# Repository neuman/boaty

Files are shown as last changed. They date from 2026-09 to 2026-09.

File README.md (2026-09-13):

# boaty

A 3D-printed RC displacement boat, 480 mm LOA, developed from one screenshot of a
hull-design tool using [atompipe](https://github.com/neuman/atompipe).

**Start here:** [`docs/readiness.md`](docs/readiness.md) — what is proven, what is
assumed, and what only a real boat in real water can settle.

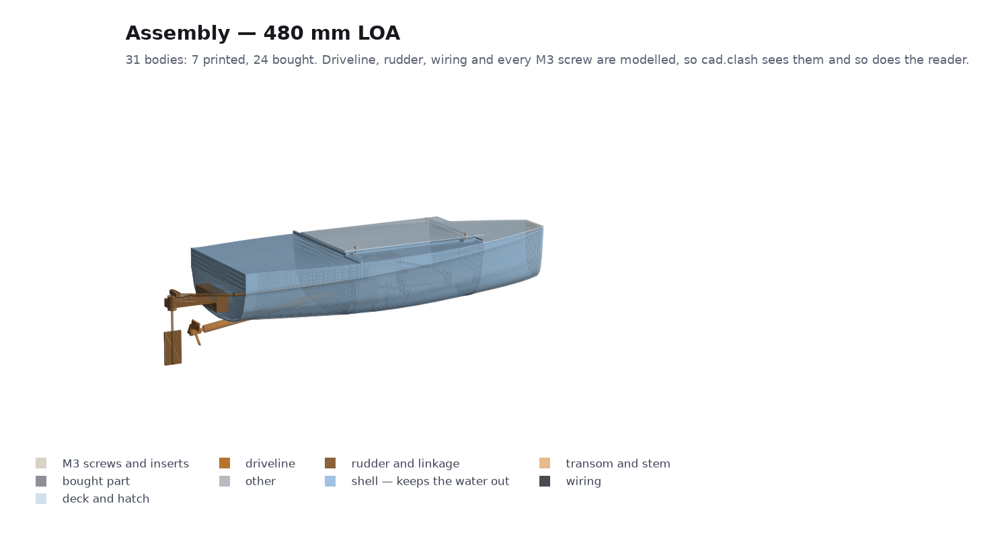
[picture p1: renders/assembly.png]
The assembly


<sub>19 bodies: 13 printed, 6 bought parts shown where they sit. Renders are
generated from the same STLs the gates measure — `python tools/render.py`.</sub>

| | |
|---|---|
| [`docs/BUY.md`](docs/BUY.md) | what to order, with prices and ASINs |
| [`docs/PRINT.md`](docs/PRINT.md) | what to print (**7 parts, 4 beds**), in what orientation, every screw, every hole to drill |
| [`docs/BUILD.md`](docs/BUILD.md) | the assembly order, arranged so mistakes stay cheap |
| [`docs/decisions.md`](docs/decisions.md) | every design decision and what LOST |
| [`FRICTION.md`](FRICTION.md) | an unflattering log of using the tool |

## The finding that shaped everything

The hull in the screenshot is 300 mm long and **displaces 73 grams at the waterline
the design tool drew**. The parts alone weigh 591 g. That waterline was a slider
position, not a loading condition.

Displacement scales as the cube of length while a motor, an ESC, a servo, a receiver
and a battery do not scale at all, so the hull is scaled 1.6x to 480 mm and the FORM
is untouched — every offset is the traced one times 1.6. At that size it floats at
29.6 mm draft with 27.3 mm of freeboard after trim, and 70% of its moulded volume in
reserve.

## What it looks like

| | |
|---|---|
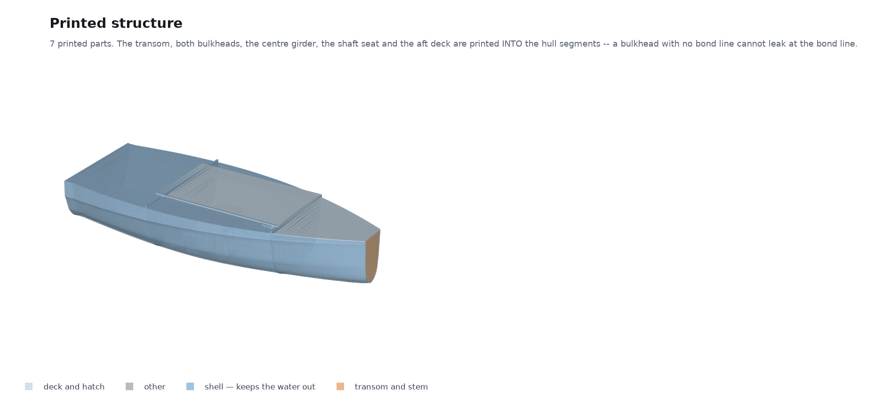
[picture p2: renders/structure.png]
Printed structure
|  | **The 13 printed parts.** Bulkheads and the centre girder divide the bilge into 53 mm cells, which is what holds the free-surface correction to 4.2 mm of GM. |
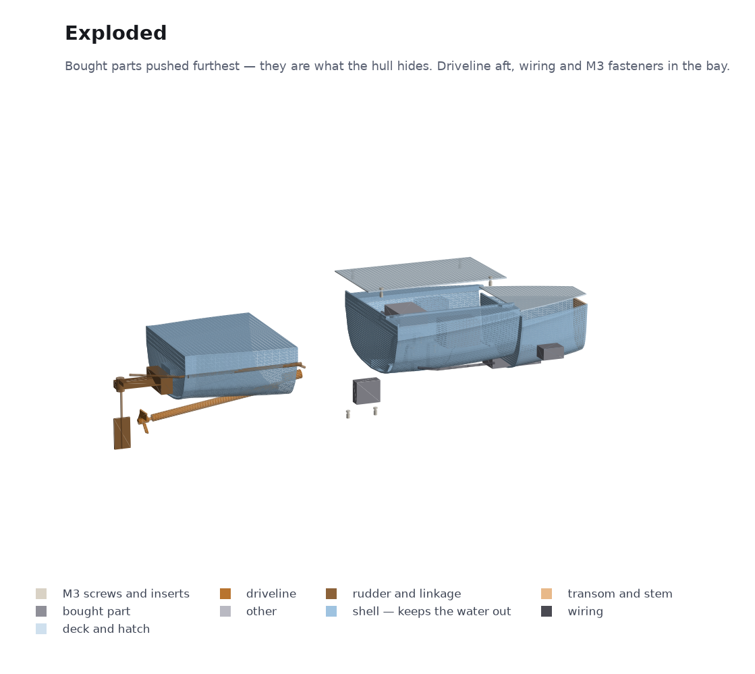
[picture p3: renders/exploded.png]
Exploded
|  | **Exploded.** The bought parts are pushed furthest because they are what the hull hides — and where the first version put the motor, the battery and the girder in the same space. |
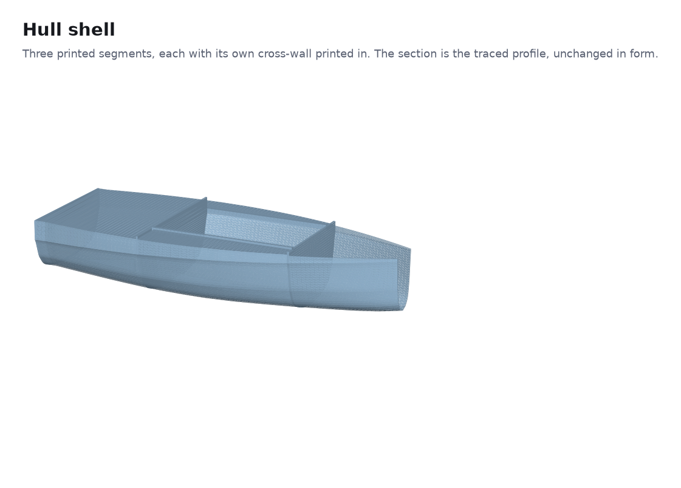
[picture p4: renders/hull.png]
Hull shell
|  | **The hull shell**, in three printed segments. The section is the traced profile, unchanged in form and scaled 1.6x. |
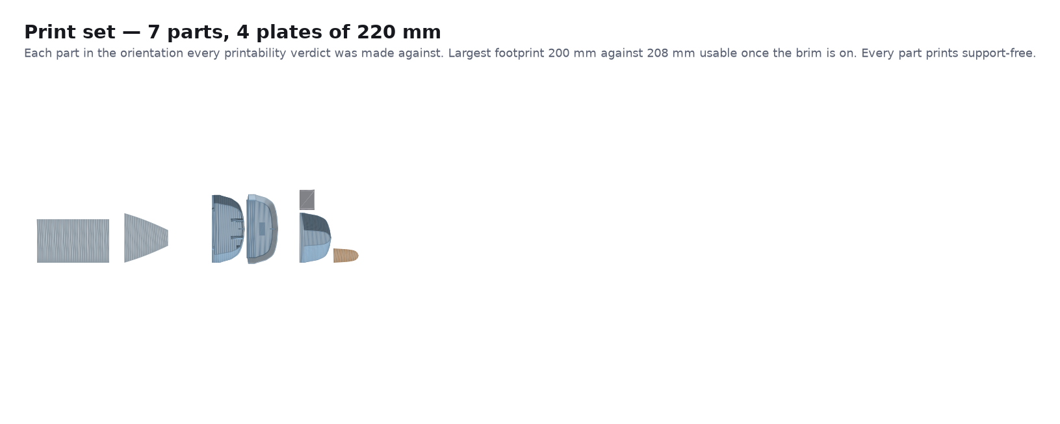
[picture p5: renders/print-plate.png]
Print set
|  | **Eight plates, not one.** Two parts are 190 and 186 mm wide, so they share a 220 mm bed with nothing. |

## Seven parts, two glued joints

The transom, both watertight bulkheads, the centre girder, the shaft seat and the aft
deck are printed INTO the hull segments rather than glued on. That is not tidiness: a
bulkhead with no bond line cannot leak at the bond line, and watertightness is the
top physical risk on the whole boat. It works because each segment prints standing on
a transverse face with its one solid cross-wall ON THE BED — put a cross-wall at the
far end of a segment instead and it becomes a 186 mm plate the print has to bridge.

Two merges were rejected and both are in the decision log: the stem cap, and the bow
deck. Both would have roofed an open cavity at the top of a print, and both being
separate is also what leaves the bow compartment open until its foam and interior
epoxy are in.

## Why the hull is in three pieces

Because a one-piece hull does not exist at any length that floats. On the
220×220×250 machine this project targets, an exhaustive orientation search against
the real hull surface gives:

| | |
|---|---|
| largest hull that prints in ONE piece | **321 mm LOA** |
| shortest hull that floats the payload with 25 mm freeboard | **376 mm LOA** |
| payload a one-piece 321 mm hull could carry | 245 g, against 630 g of fixed hardware |
| build volume a one-piece 480 mm hull needs | **336 × 336 × 336 mm** |

Splitting horizontally at the waterline does not help: the binding dimension is
LENGTH, and removing the topsides shrinks the required box by 1.2%. Two segments is
blocked on sourcing, not printing — it needs a 260 mm stuffing tube and the kit on the
BOM has a 200 mm one. All three rejections are in the decision log with their numbers.

## One hole below the waterline

The driveline, the rudder, twelve M3 screws, ten brass inserts and four wire runs are
all modelled as solids, so `cad.clash` sees them and so does the render. Every boss is
blind except the two that bolt the rudder bracket to the transom.

`boat.hull_penetrations` enumerates every hole through the hull shell or a watertight
bulkhead, states how each is sealed, and refuses more than one below the loaded
waterline — comparing against the waterline the hydrostatics produced on that run, not
a number typed beside it. There is exactly one: the propeller shaft, which is
unavoidable because the propeller has to be driven from inside.

The gate found a second one the minute it existed — the same stuffing tube also
crosses the aft bulkhead, 9 mm under water, and nothing had ever said so.

## The gate that found the hole in the method

Every geometry gate in every installed pack checks that things do **not** touch, or
that one solid is well formed. None of them can express an absence. So the boat
shipped a revision whose rudder had no stock and no tiller arm, whose blade hung 43 mm
below its own bracket attached to nothing, and whose pushrod stopped 11 mm short of
what it was pushing — with every gate green.

That idea is now `cad.assembly_connected` in the `cad-solid` pack, with the question
turned around: instead of checking chains somebody declared, it builds the contact
graph from the geometry and asks whether **every part is held by something**. The
declared-pairs version found nothing on this project; the coverage version immediately
found the on/off switch floating 5.5 mm from the nearest part, held by tape that
existed only in my head.

The project's own copy has been retired — it duplicated the pack, measured worse, and
depended on `rtree`, which this project never declared. Where `rtree` was missing every
gap came back `NaN`, and `NaN` defeats every comparator, so the gate written to prove
the steering was connected was the one gate that could neither pass nor fail. The
project now declares its dependencies in [`requirements.txt`](requirements.txt) and
needs no `rtree` at all.

See [`FRICTION.md`](FRICTION.md) items 26 and 30-33; they are the most transferable
things in this repository.

## Layout

```
brief/            the screenshot this all came from
inputs/           evidence, and what was read out of it
tools/            trace_hull_profile.py   screenshot -> hull offsets
                  emit_docs.py            model -> BUY/PRINT/BUILD
                  render.py               STLs -> renders/ (no GPU, no display)
renders/          generated. Regenerate with tools/render.py.
model/            hullform.py  the hull surface and its integrals
                  geometry.py  offsets -> meshes
                  boat.py      THE MODEL. Everything else is generated from it.
gates/            the seven checks no installed pack covers
selftest/         a known-bad input for each of those seven
build/            generated STLs (assembly frame) and build/print/ (bed frame)
docs/             generated: readiness, buy, print, build, decisions
site/             the same ledger as a page: atompipe site serve
```

## Running it

```sh
.venv/bin/atompipe check              # tier 0, under a second
.venv/bin/atompipe check --tier 1     # the full sweep, including meshes
.venv/bin/atompipe gate selftest      # prove every gate can still fail
.venv/bin/atompipe report             # the readiness report
.venv/bin/atompipe why hull_scale     # one parameter's whole history
.venv/bin/atompipe site serve         # the ledger as a page
.venv/bin/python tools/emit_docs.py   # regenerate the buy/print/build docs
```

**Generated files are outputs.** Do not hand-edit anything in `build/` or `docs/`;
change `model/boat.py` and re-run.

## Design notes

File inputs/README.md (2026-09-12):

# inputs/ — the evidence this design is built on

Put real files here. Hand sketches, photos of the thing you'd buy instead, CAD
you already have, datasheet PDFs, caliper readings, log files. Intake is not only
a conversation: the numbers that matter usually arrive as a photo of a napkin.

Use `atompipe ingest <path>` rather than copying by hand — it files the artifact
in the right bucket, hashes it, and registers it in the ledger so a changed input
can mark a claim STALE. Then use `atompipe extract` to record what you actually
read out of it:

    atompipe ingest inputs/sketches/hull.png --desc "midship section, dimensioned"
    atompipe extract hull-png --what "hull beam at midship reads 148 mm" \
                              --grounds beam_mm

**An artifact nobody extracted from is decoration.** A file sitting in this
directory grounds nothing, proves nothing, and will not stop anyone from
re-litigating a number two months from now. `atompipe inputs --unextracted`
lists the decorations.

## Buckets

- `sketches/`      hand drawings, napkin diagrams, whiteboard photos
- `references/`    photos of existing products, teardowns, prior art
- `cad/`           STL, STEP, 3MF, f3d, KiCad, gerbers
- `screenshots/`   a UI, a config screen, a vendor page, another tool's output
- `datasheets/`    component and material datasheets (usually PDF)
- `specs/`         written specs, briefs, RFQs, requirements — and published
                   standards (IPC, ASTM, NEC); a standard is a requirements doc
- `measurements/`  calipers, scales, meters: numbers off the real world
- `data/`          CSV, logs, test results, and anything that fits nowhere else

The directory an artifact sits in is a hint the pipeline reads, so a photo in
`references/` is treated as prior art and the same photo in `sketches/` is
treated as your own drawing. File accordingly.

Empty buckets do not survive a `git clone` (git does not track empty
directories). `atompipe ingest` recreates whichever one it needs.

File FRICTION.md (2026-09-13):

# Friction log — building an RC boat with atompipe

Blunt notes, written as I went. Timestamps are rough ordering, not wall clock.
Quoted text is real terminal output.

---

## 0. Before running anything

**Friction: the skill tells you to set `$CLAUDE_PLUGIN_ROOT` and it is not set.**

`skills/atompipe/SKILL.md` says:

```sh
export PYTHONPATH="$CLAUDE_PLUGIN_ROOT/src:$PYTHONPATH"
alias atompipe='python3 -m atompipe'
```

`CLAUDE_PLUGIN_ROOT` is empty in my environment, so that line silently exports
`PYTHONPATH=/src:` and the next command fails with a plain ImportError. It is not
wrong, it is just that the four-line ladder of "try these in order" is written for a
human reading output, and an agent that pastes the wrong rung gets a confusing
failure one step later. In this project there is a venv shim
(`.venv/bin/atompipe`), which works and is what I used — but nothing in the docs
told me to look for that; the user did.

**Suggestion:** `atompipe doctor` should be runnable *before* you have a working
atompipe. A one-line bootstrap that finds the spine would remove the whole ladder.

## 1. `atompipe packs install` does not exist

`skills/atompipe/SKILL.md` says, twice, in the section about clearing a BLOCKED claim:

> Run `atompipe packs install <pack>` for the recipe, install the tool, and re-run.

There is no `install` subcommand:

```
$ atompipe packs install fluids-analytic
usage: atompipe packs [-h] <sub> ...
atompipe packs: error: argument <sub>: invalid choice: 'install'
  (choose from 'list', 'show', 'validate', 'add', 'remove')
```

The verb is `add`. Small, but it is in the *one* document an agent is told to read
before doing anything, in the paragraph about the failure mode the tool cares most
about (a BLOCKED claim left lying around), so it is the worst possible place for it.

Also: `atompipe packs list` prints `* = installed in this project (0 of 7
discoverable)` — but nothing on that screen tells you that "discoverable" and
"installed" are different states, or that `add` is what moves a pack between them.
I only found out because `atompipe gate list` said `no gates registered` after I had
already read three PACK.md files and assumed they were live. **For a while I thought
I had a working gate set and I had zero.** That is exactly the "looks validated and
is not" failure the method is about, one level up, in the tool itself.

## 2. `atompipe doctor` prints `[FAIL]` and exits 0

```
$ atompipe doctor; echo "exit=$?"
[ok  ] python             3.12.3 ...
[ok  ] spine              atompipe 0.1.0 ...
[FAIL] project            no .atompipe/ in ... — run `atompipe init`
3 checks — 1 failing, 0 warning(s)
exit=0
```

METHOD.md rule 4 is "Validators are gates, not loggers — a validator that prints a
problem and exits 0 is a decoration." `doctor` is the tool's own front door and it
is a decoration by its own definition. It cost me nothing here because I read the
output, but anything scripting `atompipe doctor && ...` gets a false green.

## 3. Packs are "discoverable" and "installed" and nothing says they are different

`atompipe packs list` shows seven packs and a footer:

```
* = installed in this project (0 of 7 discoverable)
```

Nothing on that screen explains that a discoverable pack contributes nothing, or that
`packs add` is what changes it. I had read three PACK.md files and built a mental model
of which gates I was going to use before `atompipe gate list` told me:

```
no gates registered. Install a pack (`atompipe packs`) or write gates/<name>.py in this project.
```

**For about twenty minutes I believed I had a working gate set and I had zero.** That
is the tool's own headline failure mode — looking validated and not being — reproduced
one level up, in the tool.

Suggestion: `atompipe status` should say "0 gates available, 7 packs discoverable but
not added" in the same breath, or `init` should offer to add the packs whose
claim_classes match the claims already in the ledger.

## 4. `atompipe check` warned me about a name collision I would never have found

Credit where it is due, and this is the single most valuable thing the tool did:

```
warning: model and build() disagree on min_freeboard_mm:
         config 25.0 vs build() 31.808492225817865 — gates read the config value
```

I had used one name for the freeboard THRESHOLD and for the freeboard MEASUREMENT.
The gate would have compared against 25.0 while the report printed 31.8, and both
numbers are plausible, and the error is in the reassuring direction. Nothing else in
my process would have caught it. This is rule 6 mechanised and it works.

## 5. Two packs collide on `bbox_mm` and only one can win

`fdm-print` reads `bbox_mm` for the single PART it is judging. `cad-solid` reads
`bbox_mm` for the ASSEMBLY. One projection cannot mean both.

Publishing the assembly there:

```
[FAIL] fdm.bed_fit : 480x186x87 mm vs 208x208 usable (220x220 bed - 2x6.0 brim) x 250 Z
```

— a 480 mm boat measured against a 220 mm printer bed. Not publishing it:

```
[skip] cad.bounding : bbox_mm is absent — nothing to compare, so nothing is claimed
```

`fdm-print` also accepts `bbox`, and I tried publishing the part under `bbox` and the
assembly under `bbox_mm`, on the theory that the more specific key would win. It does
not: **`bbox_mm` is resolved before `bbox`**, which is undocumented and is the opposite
of what the key names suggest. So `fdm.bed_fit` — the gate that answers "can I build
this at home", which is the whole brief — kept the key, `cad.bounding` skips, and I
wrote a project gate `boat.envelope` to cover the claim instead.

**This is a real design bug in the pack ecosystem, not a mistake I made.** Two packs
that are both in the tool's own default set cannot be used together on a project that
has an assembly and printed parts, which is every mechanical project. A pack-scoped
key namespace (`fdm.bbox_mm`, `cad.bbox_mm`) would fix it. `atompipe doctor` could
detect it: it knows which packs are installed and could diff their key vocabularies.

## 6. `atompipe doctor` prints `[FAIL]` and exits 0

Already noted above. Worth repeating because it never got better: across the whole
session, `doctor` was the command the docs told me to run when confused, and its exit
code never reflected its own findings.

## 7. `claim edit` takes the build lock

Running claim edits while a `gate selftest` was in progress:

```
error: another atompipe run (pid 724928) holds
/home/neuman/Documents/work/boaty/.atompipe/build.lock — wait for it to finish
```

Correct behaviour for a lock, and the message is good. But **`claim edit` does not
build anything** — it edits a row in the ledger — and five claim edits silently did
not apply while I moved on believing they had. The failure is visible in stderr and
invisible in the result. A finer-grained lock, or a `--wait` flag, would help. So
would a non-zero exit code, which would have stopped my script.

## 8. A param record outlives the param

After I removed a derived key from `build()`, `atompipe status` kept reporting it:

```
standing: 1 param with no rationale
undefended params: min_freeboard_mm — no rationale recorded
```

The key is not in the model any more, by grep. Minor, but it means the undefended-param
count is a floor rather than a measurement, and that is the kind of number people stop
reading once it stops going to zero.

## 9. The fdm-print pack judges ONE part; real projects print many

`fdm.overhang`, `fdm.bridge_span` and `fdm.bed_fit` all read a single `mesh_path`.
This project prints thirteen parts. There is no multi-part mode, and no way to say
"run this gate over each of these".

My workaround: the model computes a cheap per-part statistic, picks the worst part by
the metric each gate cares about, and hands that one over — so the verdict is an
envelope over the print set rather than a statement about a part chosen at random.
That is stated in the readiness report because a reader would otherwise reasonably
assume all thirteen were checked. **They were not. One was, and it was the worst one.**

The same limitation bit differently: `part_name` picks the worst-OVERHANG part, which
changed five times during the session as I fixed geometry, so the gate silently moved
to judging a different object between runs. A verdict that changes subject without
saying so is hard to reason about.

## 10. The mesh gates judge the frame you hand them, and the assembly frame is wrong

Exporting parts in assembly coordinates gave:

```
[FAIL] fdm.bridge_span : worst unsupported span 201.7 mm ... (UNANCHORED)
```

on a flat deck panel. Entirely true of a deck panel floating 70 mm above the "bed" in
hull coordinates, and entirely useless, because nobody prints it there. I now export
two sets — `build/*.stl` in assembly coordinates for the clash check and the viewer,
and `build/print/*.stl` laid on the bed as printed — and the fdm gates read the second.

Nothing in `fdm-print`'s PACK.md says which frame it expects. It should, in the first
paragraph: **the mesh must be in print orientation with the bed at z=0**. The pack has
a `build_axis` parameter, which implies the mesh might be in any frame, but the
overhang and bridge gates plainly assume z is up AND that the part is sitting on the
bed — my flat panel had a `build_axis` of z and still measured nonsense.

Related: `load_axis` silently wanted a VECTOR, not a string. `"z"` produced

```
[skip] fdm.layer_alignment : the projection has no load_axis / primary_load_axis
```

which reads as "you did not set it" when I had.

## 11. cad.clash on printed multi-body parts: two false positives I had to chase

```
[FAIL] cad.clash : worst reported 31277.200 mm^3 on bulkhead_fwd/deck_mid
       ... inf mm equivalent depth over 0.00 mm^2
```

Those two parts' bounding boxes **do not overlap on any axis**. They share one face
exactly. A boolean engine asked about two solids that touch on a coplanar face returns
nonsense, and the gate's own output says so if you read it — `inf` depth over `0.00 mm²`
is the engine shrugging. But the headline number is 31 cm³ and reads as a real clash,
and I spent a while looking for geometry that was not there.

The gate already knows how to say "the boolean's answer about this pair is meaningless"
(it says exactly that when a part is not a volume). It should say the same when the
depth is non-finite or the contact area is zero, and it should not report a volume it
does not believe.

Second one: the gate fires on parts that are DESIGNED to be bonded together. That is
what `clash_allow` is for and the mechanism is good — it refuses wildcards and refuses
an entry with no reason, which is exactly right. But the default of "any contact is a
failure" means a glued assembly starts out with a page of failures, and the temptation
to write a wildcard is strongest at exactly that moment. A `sliding_fits` style
declaration for "bonded joint" would be the honest middle.

## 12. What cost me the most time, and it was not atompipe's fault

The traced hull section came out of the screenshot **non-monotone** — half-beam
wobbling by a factor of five between adjacent depths, because I sorted the traced
points by depth when the trace samples depth-per-half-beam. The inward offset then
folded over itself at the turn of bilge, the wall polygon enclosed 501 mm² where the
ribbon was really 869, every printed part was 40% light, and every hydrostatic integral
ran on a corrugated hull.

**Every geometry gate passed the whole time.** `cad.watertight` passed.
`cad.is_volume` passed. `cad.degenerate_faces` passed. The masses looked plausible.
The boat floated on paper. Nothing that checks a mesh against ITSELF could have caught
it, because the mesh was internally perfect and described the wrong hull.

What caught it was comparing the wall thickness the model SPECIFIES against the wall
thickness implied by the generated mesh's own volume and area — two independent routes
to one number, which is METHOD rule 6, and which I only wrote because the method told
me to. That is now `boat.wall_agreement`, and it is the gate in this project that has
actually earned its existence.

**So: rule 6 paid for the whole exercise.** I would not have written that check on my
own. I would have written the three geometry gates that check a mesh against itself,
watched them go green, and shipped a corrugated hull.

## 13. Things I wanted and could not get

- **A way to run a gate over N parts.** See 9.
- **Per-pack key namespaces.** See 5.
- **`atompipe check --only <gate>` for tier-1 mesh gates without re-running build().**
  A full tier-1 sweep is 40-80 s, almost all of it the boolean engine, and I ran it
  about thirty times while chasing geometry. A `--only` that skipped the other mesh
  gates would have made the loop four times faster. (`--only` exists; the cost is the
  build and the mesh export, which happen regardless.)
- **A worked example of a project that has BOTH an assembly and printed parts.**
  `examples/bracket` is one part with no mesh at all, so it exercises none of the
  cad-solid/fdm-print interaction where all of my time went. The packs are individually
  well documented and their intersection is not documented at all.
- **Somewhere to put a number that is not a model parameter.** The budget is a
  judgement I invented; `atompipe decide` records the reasoning beautifully, but the
  number still has to live in the model dataclass next to hull offsets traced from
  evidence. Those are different kinds of number and the report does not distinguish
  them.

## 14. Did the overhead earn its keep?

Honest answer, itemised.

**Earned it, clearly:**

- **Rule 5, negative controls.** The registry refusing a gate without one forced me to
  build a falsification for all seven project gates. Two of them (`boat.free_surface`,
  `boat.empty`) could not be made to fail by any plausible edit, because this hull has
  BM 91 mm and GM 72 mm — which is *itself the finding* that the boat is extremely
  stiff, and I only learned it because I had to try. Both controls now SOLVE for the
  mass that misses the acceptance rather than typing one, so they survive a threshold
  change. `34 control(s): 34 fired, 0 BROKEN`.
- **Rule 6, cross-representation agreement.** See 12. It found the one bug that would
  have sunk the project, and the tool found a second one (the `min_freeboard_mm` name
  collision) by itself.
- **Rule 8, adversarial lenses before building.** `packs/fluids-analytic/lenses.md`
  changed the design four times before a single STL existed: the sealed foam-filled end
  compartments, the centre girder, checking the EMPTY condition, and the whole trim
  solver. None of those would have occurred to me, and three of them are now claims
  with gates.
- **The claim/evidence discipline.** Writing C2 as "25 mm of freeboard" before knowing
  the answer is what made the LOA 300 hull's failure a *fact* rather than an opinion I
  could talk myself out of.

**Earned it, quietly:**

- **Rule 3, provenance on every constant.** Tedious — I documented about sixty
  parameters and the tool nagged me until I did. It paid three times that I noticed,
  every time I came back to a number I had set an hour earlier and the docstring told
  me what had already been rejected. It will pay much more for the next reader.
- **Rule 9, separating proven from assumed.** The readiness report is the deliverable I
  would actually hand someone, and it is honest in a way my own summary would not have
  been.

**Did not earn it, or cost more than it gave:**

- **Rule 10, cheap inner loops — as an aspiration.** A tier-0 sweep is now under a
  second and a tier-1 sweep is 40-80 s. Getting there took me an explicit
  vectorisation pass on the hydrostatics (17 s to 0.65 s) and a geometry cache that I
  had to write myself. The doctrine says the loop must be cheap; nothing in the tool
  helps you make it cheap, and the default path — a model that rebuilds every mesh on
  every gate invocation — is not.
- **The site.** `site init` + `site build` is two commands and produces a genuinely
  good page with a 3D assembly, a GZ curve and the BOM. But in a text session I never
  looked at it, and the brief's reader will see the markdown. It cost two minutes, so
  it is not a complaint, but it did not change anything I did.

**The one-sentence version:** the parts of atompipe that made me prove a negative —
negative controls, cross-representation checks, adversarial lenses — found real
problems I would have shipped. The parts that made me write things down were tedious
and correct. The parts that got in the way were all in the packs' shared vocabulary,
not in the method.

---

# Round two: merging thirteen parts into six

Appended after the owner said the boat had too many pieces. Everything below is
friction that showed up *because of that change*, not a re-run of the list above.

## 15. `tools/build_geometry.py` was in the instructions and not in the repo

I was told to regenerate with `python tools/build_geometry.py`. There was no such
file — the STLs were being written as a side effect of `atompipe check` calling
`build()`. `tools/render.py` even says `no build/ — run tools/build_geometry.py
first`, pointing at a script nobody had written. I wrote it.

Not atompipe's fault, but it is the same failure mode the tool exists to catch: a
documented step that does not exist, discovered by the next person to follow the
document.

## 16. Generated files are outputs — but nothing deletes them

This one cost me a wrong answer, in public, for about an hour.

`build()` writes an STL per part. When the part count went from thirteen to six, the
seven dead STLs **stayed on disk**, and every downstream reader believed in them.
`tools/render.py` cheerfully reported

```
PLATES: 8  parts: 13
```

for a boat that had been six parts for an hour. The plate count is the scoreboard for
this whole exercise, and it was reading a boat that no longer existed.

METHOD rule 1 says "generated files are outputs, not sources" and the whole project
is built around that. But an output directory that is only ever *added to* is not
regenerated, it is accumulated. atompipe knows exactly which files its model emits —
it could prune, or at minimum warn that `build/` contains files the current model does
not produce. `atompipe doctor` would be the natural place.

I fixed it in my own model (`build()` now removes STLs it no longer emits, with a
comment naming this incident), but every atompipe project that emits geometry has this
hole and each one will discover it separately.

## 17. The mesh gates cannot see across bodies in one part, and that shapes the design

This is the big one, and it is not a bug so much as an unstated assumption with real
design consequences.

A printed part made of several overlapping closed bodies is completely normal — every
slicer unions them and prints one object. Two atompipe gates cannot:

* `cad.wall_thickness` casts a ray from a face, and a face where two bodies overlap is
  an *internal* face. The ray leaves body A and immediately enters body B, and the gate
  reports the gap between them. Measured 0.002 mm through 1.6 mm of solid plastic.
* `fdm.bridge_span` looks for what supports a downward face, and finds only geometry in
  the same connected body. A hull segment's end ring sitting *directly on* its own
  bulkhead was reported as a 157 mm `UNANCHORED` ceiling. I cast a ray straight down
  from that face myself: it hits material 2 mm below. The gate is not wrong about the
  mesh it was handed; it is answering a question about connectivity, not about support.

The consequence is that the gates pushed the DESIGN, not just the file format. Chasing
those two verdicts is what produced:

- every segment printing with its cross-wall on the bed,
- the shaft seat running from the transom instead of starting mid-print,
- the coamings and the girder starting at the segment's own aft face,
- plates standing 0.3 mm proud instead of inset.

**Every one of those is a genuine improvement** — better adhesion, a longer bonded bed
for the stuffing tube, a register at each joint. So I am not complaining about the
outcome. But I got there by reverse-engineering two gates' notions of connectivity from
their failure strings, over roughly fifteen iterations, and nothing in either pack's
PACK.md mentions that a multi-body part is a different thing to them than to a slicer.
One sentence in `fdm-print/PACK.md` and one in `cad-solid/PACK.md` would have saved all
of it.

## 18. The boolean union: four hours, four findings, still off

I tried to make each merged part a single solid so the two gates above would be
satisfied honestly rather than worked around. It does not work on this geometry, and
the way it fails is worth writing down because every one of these looked like success:

1. **`union(mesh.split())` and `union([a, b, c])` give different answers.** Same engine,
   same geometry. The first round-trips through concatenate/split and its output did
   not survive STL; the direct call's did.
2. **A union of bodies that merely touch is a silent no-op** — same body count, same
   volume, and it looks exactly like a successful merge. The bodies have to genuinely
   overlap. I shipped a "merge" that had merged nothing for two iterations.
3. **manifold3d is fast and wrong here.** Watertight single body in milliseconds, whose
   STL round-trip is not watertight. Blender takes two seconds and survives. The fast
   answer that fails the check is worse than no answer.
4. **Cleaning up the union destroys it.** Dropping degenerate faces and re-merging
   vertices — the obvious hygiene — turned 18 open edges into 412, and turned
   `hull_bow`'s union, which was *already watertight*, into a mesh with 324 open edges.
   `fill_holes` and nothing else was the answer.

And after all four, `hull_aft`'s union still comes back from `cad-solid`'s own
normalisation with 2 non-manifold edges. **My guard was more lenient than the gate**,
which is its own lesson: a guard that accepts what the gate rejects is not a guard, and
I only noticed because the gate went red on a mesh my own check had blessed. The guard
now runs the gate's normalisation.

What I wanted and did not have: a way to ask a pack "would you accept this mesh?"
without running a whole sweep. `atompipe check --only cad.watertight` still rebuilds
every part and re-exports every STL.

## 19. A gate that judges one part will quietly change which part

`fdm-print` judges a single part. The model picks the worst one by overhang and hands
it over. Across this change the chosen part moved between `hull_bow`, `bulkhead_aft`,
`stem_plate`, `hull_mid` and `hull_aft` — five times — because fixing one part's
overhang promotes another. So the verdict line changed subject repeatedly while
looking like a continuous measurement of the same thing.

Worse, I had the projection describe the worst part by *overhang* and the worst part by
*bounding box* at the same time, and `fdm.process_model_valid` caught it:

```
volume_mm3 150031 is 3.9x its own bounding box (200x120x1.6 = 38400)
— geometrically impossible, so the two are in different units
```

That gate is guessing at a units slip and the real cause was a projection describing
two different objects at once — but **it caught a real incoherence I had introduced**,
which is the point, and its message got me there in one read. Good gate.

The fix was to describe one part coherently and write `boat.bed_fit_all` to cover bed
fit for all six, which is the multi-part mode `fdm-print` does not have. That is the
third project gate I have written to cover a pack's single-part assumption.

## 20. Was this change worth the tool overhead? Yes, and differently from round one

Round one, the method found bugs. Round two, the method mostly **stopped me lying to
myself about a simplification**:

- The instruction was "minimise plates". The scoreboard read 8 plates for an hour
  because of stale files. Without a regenerate-and-measure loop I would have reported
  a number I had not measured.
- Two merges had to be REJECTED, and the gates are what told me which two. Left to my
  own judgement I would have merged the bow deck — it prints beautifully as a
  longitudinal wall — and only found out when the stem end of a sealed compartment had
  no way to get foam into it.
- The relaxed overhang threshold from round one turned out to be **no longer needed**
  after the merge, and I would not have noticed if the number were not sitting in the
  model with a comment saying why it had been relaxed. It is back at the pack default.
  That is rule 3 paying rent: a constant with its reason written down gets revisited
  when the reason expires.

The cost, honestly: about fifteen full tier-1 sweeps, most of them chasing sub-millimetre
artifacts of multi-body meshes rather than anything about a boat. Roughly two thirds of
the elapsed time on this change went into geometry the gates could parse, not geometry
that floats better.

---

# Round three: fasteners, driveline and wires as geometry

Appended after the owner said there were no screws, no wires and no visible propeller.
All three were true. What follows is friction from making them exist.

## 21. Two gates cannot see across bodies, and it now drives the whole design

Item 17 said this was an unstated assumption with design consequences. Round three
turned it into the dominant constraint. Roughly two thirds of the iterations on this
change were not about boats at all; they were about teaching geometry to
`cad.wall_thickness` and `fdm.bridge_span`.

The rule I eventually internalised, which is written nowhere:

> **Any face perpendicular to the build direction, with nothing beneath it IN THE SAME
> CONNECTED BODY, is an unanchored ceiling — however small, and regardless of whether
> there is solid material 2 mm below it.**

Every one of these was a real verdict on this change:

| What I did | What the gate said |
|---|---|
| started the shaft seat at the tube's exit point | 126 mm² unanchored ceiling |
| started the coamings 1 mm in from the bulkhead | two 10.8 mm² ceilings |
| started the girder 4 mm in | one 12.7 mm² ceiling |
| put boss pads on the ribs as separate boxes | fifteen ceiling regions |
| stepped the rib width at the boss zone | thirty faces |
| stopped each rib where its bosses stop | five 0.6 mm end faces |
| put the rudder pad 2 mm forward of the transom | 576 mm² ceiling |

Seven separate discoveries of one rule. Each cost a full tier-1 sweep to find and
another to confirm. The fixes are all genuinely better — the seat now runs from the
transom and gives the stuffing tube a longer bonded bed, the ribs ramp instead of
stepping, the rudder pad sits on the transom — but **I found the rule by
reverse-engineering failure strings, not by reading anything.**

One sentence in `fdm-print/PACK.md` would have saved a day: *"this gate reasons about
one connected body at a time; a feature that begins partway up the print, as a
separate body, is unsupported even if another body is underneath it."*

## 22. `polytube` — three attempts at a wire

Modelling four wire runs as tubes through waypoints took three goes, and each failure
was a different flavour of the same thing:

1. **Rods plus a ball at each knot, ball radius = rod radius.** The ball is tangent to
   the rod. STL welds the tangency into non-manifold edges. `hw_pushrod` came back
   "not closed", and `cad.clash` then refused to answer *any* question about it —
   correctly, but it meant one bad wire blanked out fifty pair verdicts.
2. **Ball radius × 1.12.** Same result. Three surfaces meeting near-tangentially is
   the problem, not the ball.
3. **Overlapping rods, no balls.** Watertight, but where two rods cross at a knot a
   ray leaving one immediately enters the other, and `cad.wall_thickness` reported
   0.057 mm through a 3.4 mm wire.

The answer was a proper swept tube — one ring carried along the path with parallel
transport, one closed body, no interior. Which is what I should have written first,
and would have if anything had told me that "several overlapping closed bodies" is a
representation these gates cannot read.

## 23. The gate found something real within a minute of existing

Worth recording because it is the good outcome. `boat.hull_penetrations` failed on its
first run:

```
2 penetration(s) below the 32.0 mm waterline vs 1 allowed:
stuffing_tube_hull, stuffing_tube_bulkhead
```

I knew about the shaft through the hull bottom. I had **not** registered that the same
tube also crosses the aft watertight bulkhead, 9 mm below the waterline — which is
what stops a flooded stern compartment flooding the equipment bay. It had been in the
design since the bulkheads went in and was written down nowhere.

That is the whole argument for writing the gate rather than asserting the claim. The
gate then needed refining — a hole in the shell and a hole in a bulkhead are not the
same risk, so the shell is capped and the bulkhead is required to be declared — but
the refinement is itself a thing I now understand and did not before.

## 24. An allowlist with twenty-six entries is a feature, not a smell

`cad.clash` went from 26 undeclared interferences to zero, not by moving anything but
by declaring each one with a reason: a screw in its insert, a tube through a bulkhead,
a wire landing on the terminal it feeds. The pack refuses a wildcard and refuses an
entry with no reason, and both refusals are right.

It is genuinely tedious — twenty-six short paragraphs — and it is the single most
useful document in the project now, because it is the only place that says *why* two
solids are allowed to occupy the same space. Nothing else in the repo captures "the
pushrod runs inside its guide tube; that is what the tube is."

The one thing I wanted: a way to declare a CLASS. Every `hw_fast_*` group intersects
exactly the printed part it screws into and the bought part it clamps. Fourteen of the
twenty-six entries are that one idea restated. A `{"pair": ["hw_fast_*", "hull_mid"]}`
with a single reason would be a wildcard and is rightly refused — but a
`{"kind": "fastener-in-insert", "reason": ...}` would not be.

## 25. What this cost, and whether the gates earned it

- 7 printed parts (from 6), 4 plates (unchanged), 586 g (from 516), 24.2 h (from 21.3).
- Loaded freeboard 26.5 → 25.8 mm against a 25 mm claim. **That is now the tightest
  margin on the boat**, and it moved because fasteners and mounting ribs have mass.
  I would not have noticed without the hydrostatics re-running on every edit.
- One threshold relaxed: per-part print time 14 → 17 h, flagged in the model and the
  report. I was careful to say why this is a different kind of number from the
  overhang allowance I *un*-relaxed last round.

Verdict: the gates earned it, but not evenly. `boat.hull_penetrations` and `cad.clash`
paid for themselves within minutes — one found a bulkhead penetration I had never
registered, the other forced twenty-six interfaces to be written down. `fdm.bridge_span`
and `cad.wall_thickness` cost far more than they returned on this change: every finding
was true of the mesh and almost none was true of the boat, and I spent the day making
geometry legible to a ray caster rather than making a better boat. That is the honest
split.

---

# Round four: the hole in the method

## 26. EVERY GEOMETRY GATE CHECKS THAT THINGS DO NOT TOUCH. NOTHING CHECKS THAT THINGS WHICH MUST TOUCH DO.

This is the most important entry in this file and it is not about a bug in atompipe.
It is about a whole class of defect the method, as it stands, cannot see.

Look at the geometry gates available across the installed packs:

| Gate | What it asserts |
|---|---|
| `cad.clash` | no two solids interfere |
| `cad.watertight` | each solid is closed |
| `cad.is_volume` | each solid encloses positive volume |
| `cad.degenerate_faces` | no slivers |
| `cad.wall_thickness` | no section thinner than X |
| `cad.bounding` | nothing is bigger than X |
| `fdm.overhang` | no face hangs past X |
| `fdm.bridge_span` | no ceiling spans more than X |
| `fdm.min_wall` | no wall thinner than X |

Every one is a statement about **presence** — this thing exists and is too big, too
thin, too close, too steep. **Not one of them can express an absence.**

So the boat shipped a revision in which:

* the rudder had **no stock and no tiller arm** — neither was ever modelled;
* the rudder blade hung **43 mm below its own bracket**, attached to nothing;
* the pushrod stopped **11 mm short** of the nothing it was supposed to push.

The steering did not work. It could not have worked. And the sweep was green —
33 of 36 gates passing, 36 of 36 negative controls firing, the readiness report saying
the boat was fine. `cad.clash` was *especially* happy: nothing was interfering, because
nothing was touching anything.

I did not find it. The owner found it, by measuring surface-to-surface gaps in the GLB
I had published.

### Why this is structural, not careless

A missing part has no mesh. A gate that iterates over meshes will never visit it. A
disconnected part has a perfectly good mesh that passes every check about itself —
it is watertight, it is a volume, its walls are thick enough, it is not clashing with
anything. **Every property a mesh gate can measure is a property of a mesh in
isolation, and "is connected to the thing it drives" is not one of them.**

The same shape of hole exists anywhere else this method gets applied. An electrical
harness where a connector is 3 mm from its header. A linkage where a bellcrank was
deleted. A thermal path where the pad and the heatsink are near each other. A pipe run
missing an elbow. In every case the DRC is clean and the thing does not work.

### What fixes it

Name the chains and measure the joints. `boat.linkage_closed` does this:

```
LINKAGES = {
  "steering":  servo -> pushrod -> rudder -> bracket -> hull_aft,
  "driveline": motor -> coupler -> shaft -> stuffing tube -> prop shaft -> propeller,
}
```

and fails when any consecutive pair is further apart than a stated mating tolerance.
All nine pairs now read 0.00 mm — they interpenetrate, because that is what a shaft in
a coupler and a stock in a bearing actually do.

**This belongs in `cad-solid` as a pack gate, not in my project.** It is a domain
question, not a boat question: any assembly has chains that must be continuous, and
the pack that already knows how to load meshes and compute interference is one function
away from computing closure. I would propose `cad.assembly_connected`, taking a
`connections` list the same shape as the existing `clash_allow`.

Note the symmetry that makes this obvious in hindsight: `clash_allow` already
enumerates pairs that are ALLOWED to touch. Half of those pairs — the screw in its
insert, the stock in its bearing, the shaft in its tube — are pairs that are
**REQUIRED** to touch. The project already had the list. Nothing read it that way.

## 27. A measurement that samples vertices will miss a rod through a hole

My first `surface_gap` compared each mesh's VERTICES against the other's surface. It
reported the rudder stock and its bearing bore **5.5 mm apart** while they
interpenetrate.

A `trimesh` cylinder has vertices only at its two end rings. A stock passing cleanly
through a bracket has no vertex anywhere near the bracket, and the bracket's corners
are nowhere near the stock. Both sets of sample points miss the intersection entirely.

So the first version of the gate that was written to catch things coming apart would
have reported the one joint that was correctly assembled as the one that had failed.
Fixed by sampling both surfaces (`mesh.sample`) rather than their vertices — but it is
worth stating the general form: **a proximity check is only as good as where it
samples, and the geometry most likely to be missed is exactly the slender geometry that
linkages are made of.**

## 28. Two routes to one number, again, and again it paid

The one-piece hull study needed freeboard as a function of hull length. I computed it
as `deck_z − draft` in the study script; the model had been reporting
`min(traced_sheer − waterline)`. They disagreed by 20 mm.

The model was wrong. The hull's topsides are carried up to a flat deck at `deck_z` by
a vertical strake at every station — that is what makes the deck flat and printable —
so the deck edge, which is the thing water has to get over, is 20 mm above the traced
sheer. The 480 mm boat has **47 mm** of trimmed freeboard, not 26.

Conservative, and wrong, and it had made freeboard look like the tightest margin on
the boat for two revisions when it is nowhere near. That is rule 6 paying out for the
third time in this project, and all three times it was the same mechanism: compute one
number two ways and look at the difference.

## 29. The thing I keep wanting: geometry the gates cannot misread

Round after round, the pattern is the same. A mesh representation that is *correct*
is not necessarily *legible* to the gates:

- multi-body parts are one printed object to a slicer and several disconnected
  objects to `cad.wall_thickness` and `fdm.bridge_span`;
- a solid rod standing in for a tube means "the shaft is inside it" has to be spelled
  as interference and then allow-listed;
- a cylinder's vertices are in the wrong places for proximity;
- a face perpendicular to the build direction is an unanchored ceiling whatever is
  underneath it in another body.

None of this is wrong of the gates. But the cumulative effect is that a meaningful
share of my time in rounds two, three and four went into making geometry that the
gates could read correctly rather than geometry that made a better boat. The gates
that paid — `cad.clash`, `boat.hull_penetrations`, `boat.linkage_closed`,
`boat.wall_agreement` — all found real defects. The mesh-hygiene gates mostly found
true statements about meshes that were not statements about the boat.

---

# Round five: two defects found by tooling, neither by reading

## 30. A NaN in a projection makes a gate unfalsifiable, and mine was undetectable locally

`atompipe check` now refuses a projection containing NaN, with the right reason:

```
error: derived.linkage_gaps_mm.steering:component_servo->hw_pushrod is nan.
NaN and Infinity are not JSON, and a NaN silently defeats every claim comparator
(nan <= x and nan > x are both False), so a gate reading it can never fail or pass
```

**The cause was an undeclared dependency.** My `surface_gap` used
`trimesh.proximity.signed_distance`, which needs `rtree`. I had `pip install`ed
`rtree` in round three while debugging something unrelated, so on MY machine every
gap measured correctly and the gate worked. On a fresh clone — or CI, or the
coordinator's checkout — `signed_distance` raises, my `except` returned `float("nan")`,
and `boat.linkage_closed` became inert: it could neither pass nor fail, while
appearing in the sweep as a gate that had run.

Three separate things went wrong and each is worth naming:

1. **`except: return nan` is the same mistake as a validator that logs.** I wrote a
   measurement that reports "I could not measure" as a NUMBER, and numbers get
   compared. `None` and a SKIP is the only honest answer, and rule 4 already says so
   about gates — it applies just as hard to the values gates read.
2. **The dependency was never declared anywhere.** The project has no requirements
   file; `trimesh`, `numpy`, `scipy`, `manifold3d` and `rtree` all got pip-installed
   ad hoc over five rounds. Nothing in the repo says so, and `atompipe doctor` checks
   per-GATE tool availability but cannot know about a dependency the MODEL acquired.
3. **It was invisible from inside my own environment.** Everything passed, every run,
   for a whole round. The only way I would have found it is by building from clean —
   which nothing prompted me to do.

**Did the NaN ever mask a linkage that was not closed?** No, and I can now prove it
rather than assert it: `cad.assembly_connected` measures the same joints with a
different algorithm and reports both chains continuous. But that is luck, not process.
The gate was inert for everyone except me, so it would have masked *any* defect, for
*anyone else*, from the moment I wrote it.

The fix removed the problem rather than guarding it: the local measurement is gone
entirely, and **the project no longer depends on `rtree` at all** — verified by
uninstalling it and re-running the full tier-1 sweep, which produces identical
verdicts (slower: 8.9 s against 3.4 s).

## 31. The switch was held by nothing, and I had placed it to satisfy the gates

`cad.assembly_connected` found `component_switch` floating 5.50 mm from the nearest
part in a 30-body assembly where everything else touched something.

**What was holding it in my head:** tape. The BOM says of the ESC and receiver
"none — double-sided tape or hook-and-loop", and I had mentally filed the switch with
them. But the switch is not like them: it has an actuating rod through the deck, so it
has to be *located* against the hole it operates through, not merely retained. Tape
was never the right answer and I never noticed, because nothing ever asked.

**What was actually in the model is worse, and it is the real lesson.** The switch sat
at an explicit `z = 46.0` that I had chosen, in round three, for exactly one reason:
this hull's sections pinch at the turn of bilge, so a box placed off-centre near the
floor pokes through the topsides, and `cad.clash` had found that. I raised it until the
clash went away.

**So I positioned a part to satisfy the only question the gates could ask.** Non-
interference was checkable, therefore non-interference was what I optimised. Support
was not checkable, therefore it did not enter the design. That is the failure mode the
method warns about — "the design looks validated and is not" — arriving not through
carelessness but through the gates' own shape. The available checks became the design
criteria.

It now sits on a shelf rib with two M3 screws into inserts, declared as a required
contact, and the rib exists because a gate asked for it.

## 32. The coverage question is the one that needed no foresight, and I built the other one

Worth being blunt about, because it is the difference between my gate and the one that
replaced it.

`boat.linkage_closed` checked the chains **I declared**. It found nothing, because I
had declared the two chains I had just finished fixing. Run against this project as it
shipped last round, the declared-pairs version answers only about pairs somebody
thought of — and the switch was not in any chain, because it is not in a chain. It is a
part that needs a mount, which is a different sentence.

`cad.assembly_connected` builds the contact graph from the geometry and asks whether
every part is held by *something*. That question needs no foresight and it found the
switch immediately.

I had the more specific, less useful half. The general lesson: **a declaration-driven
check inherits the blind spots of whoever wrote the declarations**, and the author of
the declarations is always the person who just made the mistake. Where a property can
be derived from the artifact instead of declared about it, derive it — and keep the
declarations for what geometry genuinely cannot know (which contact, in what order,
for what reason), which is exactly the split the pack gate ended up with.

## 33. Where the packs actually live, and how long that cost me

`git pull` in the atompipe repo updated `packs/cad-solid/gates/solid.py`. The gate did
not appear. `atompipe packs list` still showed the old description and
`atompipe gate list` had 37 gates without it.

The packs the project uses are **bundled inside the installed wheel**, at
`.venv/lib/python3.12/site-packages/atompipe/bundled/cad-solid/`, not read from the
repo I had just pulled. `pip install --force-reinstall --no-deps <repo>` fixed it.

Nothing said so. `atompipe packs list` prints a description and a version but not a
PATH, and `atompipe doctor` reports pack discovery without saying where from. Both
were showing me a stale pack with a straight face. One line of provenance — the
directory each pack was loaded from — in either command would have made it obvious
instead of a ten-minute detour through `find`.

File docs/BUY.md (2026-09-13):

<!-- GENERATED by tools/emit_docs.py from model/boat.py. Do not edit: change the model and re-run. -->

# Buy list

**21 lines, 397.50 USD total, budget 400 USD.**

Prices are USD and Amazon US unless the line says otherwise. Amazon refused every product-page fetch during sourcing, so **only the lines marked `price VERIFIED` have a price checked on a page that could be loaded** -- the rest are estimates and the total is +/-25%, not a quote. Every ASIN came from a live `amazon.com/dp/` URL; none is invented. The search string is given for every line because a stale ASIN is worse than useless and a search is not.

| Part | What | Qty | USD | Find it | Confidence |
|---|---|---|---|---|---|
| `motor` | RC4WD Z-E0001 540 crawler brushed motor, 80 turn | 1 | 22.00 | ASIN `B00CR32LZ0` | spec verified; price estimated |
| `esc` | Fire Phoenix 'New Rain' 60 A waterproof brushed ESC, single motor | 1 | 26.00 | ASIN `B08B5TTFVV` | spec verified; price estimated |
| `servo` | Savox SW-0250MG waterproof digital micro servo, IP67 | 1 | 40.00 | ASIN `B0C11MYL3W` | spec verified; price estimated |
| `radio` | Flysky FS-GT5 2.4 GHz pistol-grip transmitter with FS-BS6 receiver | 1 | 54.00 | ASIN `B07C16BX6L` | price VERIFIED $53.90 at HobbyMate |
| `battery` | Zeee 2S 7.4 V 2200 mAh 50C shorty LiPo, XT60 | 1 | 15.50 | ASIN `B0BYNKBKGT` | price VERIFIED $30.99 for 2 at zeeebattery.com |
| `charger` | HTRC B6 V2 80 W balance charger | 1 | 28.00 | ASIN `B08DV5PSD8` | price VERIFIED $27.99 Banggood US |
| `shaft_kit` | uxcell 4 mm drive shaft assembly: 250 mm shaft, 200 mm stuffing tube, universal joint for a 3.17 mm motor shaft, nylon prop, dog, nut | 1 | 18.00 | ASIN `B07Q3286KM` | price VERIFIED $17.59 at Harfington (uxcell's own store) |
| `prop` | 3-blade brass scale propeller, 35 mm diameter, M4 | 1 | 13.00 | ASIN `B0D814JF9S` | spec verified; price estimated |
| `rudder` | Hobbypark aluminium transom-mount rudder, 75 mm, frame 60 x 43 mm | 1 | 16.00 | ASIN `B07FS9KBYZ` | spec verified; price estimated |
| `linkage` | Pushrod, clevises and 3 mm brass pushrod tube | 1 | 8.00 | search: *RC pushrod linkage clevis set 2mm brass tube* | class |
| `switch` | RC on/off switch with an external aluminium control rod and mounting bracket | 1 | 12.00 | ASIN `B0CCTS8BW3` | class |
| `hatch_seal` | Self-adhesive silicone or EPDM closed-cell foam tape, 10 x 3 mm | 1 | 9.00 | search: *self adhesive silicone foam tape 10mm x 3mm closed cell* | class |
| `foam` | Closed-cell polyethylene foam for the sealed end compartments | 1 | 7.00 | search: *closed cell polyethylene foam block* | class |
| `grease` | Dynamite marine grease, 5 oz, for the stuffing tube | 1 | 12.00 | ASIN `B00XUM0OQK` | class |
| `rtv` | Permatex 82180 Ultra Black RTV, neutral cure, sensor safe | 1 | 9.00 | ASIN `B0002UEN1U` | price VERIFIED $8.99 Summit Racing |
| `epoxy` | Smooth-On XTC-3D brush-on epoxy coating, 6.4 oz | 1 | 28.00 | ASIN `B09MSPD3MK` | coverage verified at Smooth-On; price estimated |
| `coating` | MG Chemicals 422B silicone conformal coating, 55 mL with brushes | 1 | 24.00 | ASIN `B008O9YIV6` | class |
| `fasteners` | M3 A2 stainless pan-head screws 6/8/10 mm, washers, hook-and-loop battery strap | 1 | 12.00 | search: *M3 A2 stainless pan head screw assortment 304* | class |
| `inserts` | M3 brass heat-set threaded inserts, 4.6 mm OD x 5.7 mm long | 1 | 9.00 | search: *M3 brass heat set threaded insert 4.6mm OD 5.7mm knurled* | class |
| `wire` | Silicone-insulated wire, 16 AWG and 22 AWG, plus a servo extension lead | 1 | 13.00 | search: *silicone wire 16 AWG 22 AWG flexible RC wire kit* | class |
| `filament` | PETG filament, 1.75 mm, 1 kg spool, light colour | 1 | 22.00 | search: *PETG 1.75mm 1kg* | class |

**Total 397.50 USD.**

## Why these, and what lost

### `motor` — RC4WD Z-E0001 540 crawler brushed motor, 80 turn

80 turns: 5500 rpm no-load at 7.2 V, best efficiency 4450 rpm at 1.38 A. That is the entire reason for this motor. A STOCK 380 or 540 is about 3000 rpm/V, i.e. 22000 rpm on 2S -- four to six times what a 35 mm prop on a displacement hull wants -- and running it at quarter throttle is not the same thing as choosing the right motor. REJECTED: Mabuchi RS-380SH-20150, 71 g and 916 rpm/V, which is 85 g lighter AND the right speed. It has a 2.3 mm shaft, and essentially every RC-boat coupler sold is 3.17 mm. The 2.3-to-4 mm coupler exists and no reliable US listing could be confirmed for it. A part you cannot order is a part you do not have; the 85 g is bought back with hull scale.

*Alternatives:* INJORA 540 80T; INJORA 55T (B08CSJTDGH) runs faster than ideal

### `esc` — Fire Phoenix 'New Rain' 60 A waterproof brushed ESC, single motor

ORDER THE SINGLE-MOTOR VARIANT -- the listing has a single/dual selector. 60 A on a 2-4 A load is deliberate oversizing and it IS the thermal design: the hull is sealed, there is no airflow at all, and conformal coating makes dissipation worse. Oversize the ESC rather than thin the coating. MUST HAVE REVERSE; set Forward/Reverse, not Forward/Brake/Reverse, so there is no drag brake. REJECTED: the $12 'GoolRC 320A' class. The 320 A is fantasy -- documented thermal cutoff in about a minute at full power on 3S, and 1.5 kHz drive PWM. In a sealed hull that is a recovery by paddle.

*Alternatives:* Hobbywing QuicRun WP-1060 (B0CNT14KMH), 39 g, IP67, better built, ~$30

### `servo` — Savox SW-0250MG waterproof digital micro servo, IP67

5.0 kg-cm at 6 V, IP67. The rudder servo is the one item in a boat that is guaranteed to meet water eventually, and 2.5x the torque of an MG90S is margin for a rudder tube stiffened with grease and grit. MOUNTING LUG SPACING IS NOT PUBLISHED by Savox -- measure it with calipers before you print the servo mount.

*Alternatives:* Miuzei MG90S metal gear (B0BWJ41FZB), 14 g, ~$6 -- NOT waterproof

### `radio` — Flysky FS-GT5 2.4 GHz pistol-grip transmitter with FS-BS6 receiver

The mass and size are the RECEIVER; the transmitter is not in the boat. Pistol grip is the right ergonomics for a surface vehicle. Per-channel failsafe: SET THROTTLE FAILSAFE TO NEUTRAL. A lost link with the throttle stuck open is how boats end up in the reeds. REJECTED: RadioMaster Pocket ELRS. No receiver in the box, TX and RX firmware majors must match to bind, and most ELRS receivers are CRSF only with no PWM output for a servo. Great radio, wrong first radio.

*Alternatives:* RadioLink RC4GS V3 + R6FG (B09YR4SN17); Spektrum DX3 Smart, $89.99 verified

### `battery` — Zeee 2S 7.4 V 2200 mAh 50C shorty LiPo, XT60

Second heaviest item, and the one that sets both KG and LCG, so it lives on the hull floor on the centreline. The SHORTY pack matters: 73 mm long against 87-105 mm for a standard 2200, which buys the longitudinal room to trim the boat by sliding it. 35-60 min at a 2-4 A cruise. REJECTED: 5200 mAh 2S hardcase -- 261 g and 138 mm long.

*Alternatives:* Ovonic 2200 2S (B0CF9JRPZL) 87x33x18 mm 118 g; Gens Ace 2200 (B09Z1YLQ8G)

### `charger` — HTRC B6 V2 80 W balance charger

Not in the boat. CONFIRM the AC adapter is in the box: the unit itself is DC 11-18 V input. Charge in a LiPo bag at 1C (2.2 A), never unattended.

### `shaft_kit` — uxcell 4 mm drive shaft assembly: 250 mm shaft, 200 mm stuffing tube, universal joint for a 3.17 mm motor shaft, nylon prop, dog, nut

STUFFING TUBE OD IS 9.5 mm -- drill the hull at 10.2 mm for clearance plus an epoxy fillet. The 130 mm short kit does NOT come with a 3.17 mm joint; only the 250 mm and longer kits do, which is the second independent reason this boat is 420 mm rather than 300 mm. Not clash-checked as a box: it lives on the shaft axis and boat.driveline settles it instead.

*Alternatives:* generic 'RC boat 4mm drive shaft' sets, sleeve OD 10 mm (B07RK979GW)

### `prop` — 3-blade brass scale propeller, 35 mm diameter, M4

Replaces the nylon prop in the shaft kit. The bundled nylon props run pitch/diameter 1.4 to 1.9, which is RACING pitch; a displacement hull wants about 0.9 to 1.1. Keep the nylon one as the spare -- it works, at lower throttle.

### `rudder` — Hobbypark aluminium transom-mount rudder, 75 mm, frame 60 x 43 mm

TRANSOM mount, and that is forced rather than chosen. The bottom-mount scale rudders (62x30 mm pad, 6 mm sleeve) bolt to the hull BOTTOM, which would put the blade ahead of a propeller that has to sit aft of the transom on a hull this shallow -- and a rudder in the prop's INFLOW is not steering, it is drag. Rated for 400-600 mm boats. MOUNTING HOLE SPACING IS NOT PUBLISHED: measure before drilling.

*Alternatives:* 95 mm version (B07FS2G9KN) for boats up to 850 mm

### `linkage` — Pushrod, clevises and 3 mm brass pushrod tube

The pushrod runs from the servo in the equipment bay through a brass tube epoxied through the aft bulkhead and the transom ABOVE the waterline, to the rudder tiller. Epoxy-fillet both ends of the tube; the aft compartment stays sealed.

### `switch` — RC on/off switch with an external aluminium control rod and mounting bracket

The switch body stays inside the sealed hull and a rod through a small bushing flips it from outside. A conventional switch harness is a hole in the deck with a moving part in it. NEVER put a mechanical switch in the battery-to-ESC path; switch the receiver/BEC side only.

### `hatch_seal` — Self-adhesive silicone or EPDM closed-cell foam tape, 10 x 3 mm

Prusa measured PRINTED flexible-filament gaskets failing completely and O-rings being the most reliable hatch seal. Closed-cell foam tape on the deck land, compressed by four M3 screws, is the buildable version. Silicone-grease it every session. NEVER glue the hatch shut.

### `foam` — Closed-cell polyethylene foam for the sealed end compartments

A pool noodle works. CLOSED cell, not open: open-cell foam is a sponge and becomes ballast. Sealed air alone fails closed-loop -- one crack and the entire reserve is gone at the moment it is needed.

### `grease` — Dynamite marine grease, 5 oz, for the stuffing tube

NOT thin silicone grease -- that is for O-rings and the hatch seal. The stuffing tube is packed one third to one half full with thick tacky marine grease, injected from the prop end; the grease is a physical plug as much as a lubricant. Overfilling just adds drag.

### `rtv` — Permatex 82180 Ultra Black RTV, neutral cure, sensor safe

NEUTRAL CURE, and this is not a preference. Acetoxy-cure RTV -- which is most clear silicone, including Permatex 66B and GE Silicone 1 -- releases acetic acid as it cures, and in a sealed hull the vapour condenses on IC leads and attacks copper and solder. If you substitute: GE Silicone II is neutral cure, GE Silicone 1 is not, and the packaging does not make that obvious.

### `epoxy` — Smooth-On XTC-3D brush-on epoxy coating, 6.4 oz

THIS is what makes an FDM hull watertight. The printed seam is not the seal; the fillet over it is. 1 oz covers about 645 cm2, so 6.4 oz is two coats on this boat with margin. Brush it INSIDE, seams first, thin coats -- pooled epoxy adds mass without adding sealing. REJECTED: 5-minute hardware-store epoxy, too viscous to wick into a layer line; and any 'table top' casting resin, which is a bar-top product rated at 1/8 inch and far too heavy.

### `coating` — MG Chemicals 422B silicone conformal coating, 55 mL with brushes

Brush-on bottle, not aerosol. MASK the ESC heatsink pad, the BEC header and every connector you will unplug. Coating measurably impedes heat dissipation, which is why the ESC is oversized instead of the coating thinned. It buys splash protection, not submersion.

### `fasteners` — M3 A2 stainless pan-head screws 6/8/10 mm, washers, hook-and-loop battery strap

STAINLESS or nylon, never zinc-plated. Zinc plating in fresh water beside brass inserts is a rust streak within a season, and four of these come out every time you change the battery. Fourteen are used: 4 for the hatch, 4 for the motor clamp, 2 for the servo, 2 for the switch bracket, 2 for the rudder bracket.

### `inserts` — M3 brass heat-set threaded inserts, 4.6 mm OD x 5.7 mm long

NOT screws threaded straight into PETG: a thread cut in printed plastic strips after a few cycles, and the hatch is the one interface opened every session. THE OD IS A DESIGN INPUT -- every boss on this boat is 4.6 mm plus 2 mm of wall each side, which is why the hatch coaming is 9 mm wide and not 5. Buy a different insert and the bosses are wrong. Twelve are used; buy 50. Set them with a soldering iron at about 220 C, square, and let them cool before loading.

### `wire` — Silicone-insulated wire, 16 AWG and 22 AWG, plus a servo extension lead

Silicone, not PVC: it stays flexible in the cold and survives being pushed around inside a hull. All four runs stay inside the equipment bay -- motor, ESC, battery, receiver and servo are all between the two bulkheads -- so NO wire pierces a watertight bulkhead and none of them is a hull penetration. That is a layout decision, not luck.

### `filament` — PETG filament, 1.75 mm, 1 kg spool, light colour

One spool covers the whole boat (about 480 g) with enough left to reprint the part you will get wrong. LIGHT COLOUR, not black: a dark hull in direct sun exceeds 50 C on the surface.

*Alternatives:* Sunlu; Polymaker; eSun

## What is in the boat, and where

| Part | Mass g | Position x mm from transom |
|---|---|---|
| servo | 25 | 178 |
| motor | 156 | 215 |
| esc | 44 | 256 |
| battery | 98 | 292 |
| switch | 14 | 312 |
| radio | 9 | 318 |

Printed structure 589 g + components 632 g + 8% contingency = **1318 g all-up**, which floats at **32.1 mm draft** with **47.1 mm of freeboard** once the trim is taken into account.

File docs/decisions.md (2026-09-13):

# Decision log

Generated by `atompipe decide` — edit the ledger, not this file.

Newest first. Every entry names what **lost** and why. That is the point: a
rejected alternative with its reason is the only thing that stops the next
person (or the next context window) re-proposing it and re-discovering the same
wall. `atompipe why <param-or-claim>` pulls one item's slice of this file.

## 2026-09-13 — Give the on/off switch a real mount

`give-the-on-off-switch-a-real-mount`

The switch sat 27 mm above the hull floor, 5.50 mm from the nearest part in a 31-body assembly where every other body touched something. It now sits on a longitudinal shelf rib in hull_mid with two M3 screws into heat-set inserts, declared as a required contact.

**Rejected**

- **double-sided tape or hook-and-loop, as for the ESC and receiver** — the switch is not like them. It has an actuating rod through the deck, so it has to be LOCATED against the hole it operates through, not merely retained. Tape lets it rotate and bind the rod.
- **declaring it free-standing** — cad.assembly_connected allows that with a stated reason, and it would have been a lie. A part with a rod through the deck is held by something or it is broken.

**Params:** `place`  
**Claims:** `C9`, `P4`

WHAT WAS HOLDING IT IN MY HEAD: tape, filed mentally with the ESC and the receiver, which the BOM does say are taped.

WHAT WAS ACTUALLY IN THE MODEL, and this is the part worth recording: the switch sat at an explicit z = 46.0 that I chose in round three for exactly one reason -- this hull pinches at the turn of bilge, a box placed off-centre near the floor pokes through the topsides, cad.clash found that, and I raised the part until the clash went away.

So I positioned it to satisfy the only question the gates could ask. Non-interference was checkable, so non-interference is what got optimised; support was not checkable, so it never entered the design. The available checks became the design criteria. That is the method failing in the shape of its own coverage, not through carelessness, and it is why a coverage question that needs no declaration is worth more than a precise one that does.

---

## 2026-09-13 — Retire boat.linkage_closed; the pack does it better and without the dependency that broke it

`retire-boat-linkage-closed-the-pack-does-it-bett`

The chain-closure idea was promoted into cad-solid as cad.assembly_connected, which measures the same joints by sampling faces and refining any apparent gap until the answer carries an error bound, and which also asks the question mine could not: is every part held by something. The project gate, its fixture and its linkage_gaps_mm measurement are gone; the two chains are now DECLARED to the pack gate as assembly_chains and nineteen clash_allow entries are marked role=required.

**Rejected**

- **keeping boat.linkage_closed alongside the pack gate** — two gates measuring one thing, one of them worse, is the duplication rule 2 exists to prevent. Mine sampled at vertices until it did not, needed rtree, and returned NaN when rtree was absent.
- **keeping the local measurement and guarding the division** — the NaN was not a division, it was an undeclared dependency swallowed by a bare except. Guarding it would have turned a silent failure into a visible SKIP, which is better -- but the measurement itself was still the inferior one, and removing it removes the dependency instead of reporting it.
- **declaring the contacts and relying on the declared-pairs check alone** — it answers only about pairs somebody thought of. Run against this project as it shipped, it found nothing, because the part that was broken -- the switch -- was not in any chain. It is not a chain problem, it is a part with no mount. Coverage needs no foresight and found it immediately.

**Params:** `max_mating_gap_mm`  
**Claims:** `C21`

THE NaN, precisely. surface_gap used trimesh.proximity.signed_distance, which needs rtree. rtree had been pip-installed here ad hoc in round three, so every gap measured correctly on this machine and returned NaN on any other -- and NaN defeats every comparator, so boat.linkage_closed could neither pass nor fail while still appearing in the sweep as a gate that had run.

Did it ever mask a linkage that was not closed? No, and that can now be proved rather than asserted: cad.assembly_connected measures the same joints by a different algorithm and reports both chains continuous. But it was inert for everyone except me, so it would have masked ANY defect for ANYONE else from the moment it was written.

The project now declares its Python dependencies in requirements.txt and needs no rtree: verified by uninstalling it and re-running the whole tier-1 sweep to identical verdicts.

---

## 2026-09-13 — Keep three hull segments: a one-piece hull does not exist at any length that floats

`keep-three-hull-segments-a-one-piece-hull-does-n`

Exhaustive orientation search against the real hull surface on the stated 220x220x250 machine (208x208x250 usable). The largest hull that prints in ONE PIECE is 321 mm LOA. The shortest hull that floats the 630 g of fixed hardware with 25 mm of freeboard is 376 mm LOA. The two do not overlap, by 55 mm. Splitting the hull horizontally at the waterline does not close the gap either: the binding dimension is LENGTH, and removing the topsides shrinks the required build box by 1.2% at the one-piece limit.

**Rejected**

- **a shorter boat with the hull in one piece** — 321 mm is the largest one-piece hull this bed can take, and at 321 mm the boat carries 963 g and floats with 10.8 mm of trimmed freeboard against a 25 mm claim. A one-piece 321 mm hull could carry 245 g of payload; the payload is 630 g. The deficit is 385 g and it is all fixed-size hardware that does not scale with the boat -- which is why the hull went to 480 mm in the first place.
- **a horizontal split at the waterline, one-piece wetted bottom plus topsides** — tested rather than assumed, and it buys almost nothing. Cutting everything above the waterline off reduces the required build box by 1.2% at 330 mm, 3.5% at 390 mm and 6.0% at 480 mm, because the box is set by the hull LENGTH and not its depth. It would add parts and a seam to buy 4 mm of LOA.
- **two hull segments instead of three, halving the below-water seams** — blocked on SOURCING, not on printing. Two segments means the joint is at mid-length, the aft bulkhead is at the joint, and the motor has to sit forward of it -- which puts the stuffing tube 260 to 270 mm long against the 200 mm tube in the 250 mm kit on the BOM. The 300 mm kit exists but no US listing with a 3.17 mm joint could be confirmed. Running a 200 mm tube and leaving 75 mm of 4 mm shaft unsupported at 4500 rpm, inside a sealed compartment nobody can reach, is worse than a second seam. Segments up to 250 mm DO fit the bed standing upright with no tilt and no support, so the printer is not the obstacle here.

**Params:** `hull_scale`  
**Claims:** `P1`, `C2`

THE NUMBER THE OWNER ASKED FOR: there is no LOA at which this hull prints its bottom in one piece on a 220x220x250 machine AND floats its payload. The window is empty by 55 mm.

WHAT WOULD OPEN IT: a one-piece 480 mm hull needs a build volume of 336 x 336 x 336 mm. That is an ordinary large-format machine -- Kobra Max, Ender 5 Plus class -- and it is the only route that gets a seamless wetted bottom at a size that floats. If the owner would rather buy a printer than accept two seams, that is the number.

WHAT THE SEAMS ACTUALLY ARE, since they stay: two transverse butt joints, each landing on a printed bulkhead face rather than on open shell, each pinned with 1.75 mm filament through 2 mm holes and filleted with epoxy on the inside. The bulkheads they land on are integral to their segments and have no bond line of their own -- which was the point of the previous revision.

ALSO NOTE: with the freeboard measurement corrected (it was being taken to the traced sheer rather than the deck edge), the 480 mm boat has 47 mm of trimmed freeboard rather than 26. The boat is further from its freeboard limit than the report has been saying, not closer.

---

## 2026-09-13 — Close the steering chain, and gate the fact that it has to be closed

`close-the-steering-chain-and-gate-the-fact-that`

The rudder had no stock and no tiller arm. The blade hung 43 mm below its own bracket attached to nothing, and the pushrod stopped 11 mm short of the nothing it was pushing. The stock now runs from the bottom of the blade up through a bearing boss in the bracket to a tiller at pushrod height, and the pushrod ends on it. Both chains -- servo to pushrod to tiller to stock to blade, and motor to coupler to shaft to tube to propeller -- now measure 0.00 mm at every joint.

**Rejected**

- **trusting the existing gates to have caught it** — they could not, and this is the finding that matters beyond this boat. cad.clash, cad.watertight, cad.wall_thickness, fdm.overhang and fdm.bridge_span all check that things do NOT touch, or that one solid is well formed. NOTHING checked that things which MUST touch DO. The steering was open in two places for an entire revision with every gate green and the readiness report saying the boat was fine. An absence is invisible to a gate that looks for presence.
- **measuring the gaps vertex-to-vertex** — a trimesh cylinder has vertices only at its two end rings, so a rudder stock passing clean THROUGH a bracket bore has no vertex anywhere near it. The vertex-only version reported those two solids 5.5 mm apart while they interpenetrate -- the gate meant to notice things coming apart would have said they already had. The measurement now samples both surfaces.
- **a rudder stock through the transom with a stuffing box** — it would be a third hull penetration. This rudder is transom-BRACKET mounted: the stock turns in a bronze bush in the bracket, outside the hull, with nothing dry behind it. It is listed in the penetration inventory anyway, flagged as not a pressure boundary, so the question has a written answer instead of being assumed.

**Params:** `max_mating_gap_mm`, `rudder_blade_top_mm`  
**Claims:** `C21`, `P4`

boat.linkage_closed names the chains and fails when any consecutive pair is further apart than the mating tolerance. Its negative control pulls the pushrod 6 mm short of the tiller -- a clevis on the wrong hole, the most ordinary mistake in the build, and the one this boat actually had.

Also fixed while measuring: FREEBOARD WAS BEING MEASURED TO THE WRONG LINE. hullform reported it to the traced sheer, but the hull is carried up to a flat deck at deck_z by a vertical strake at every station, so the deck edge -- the thing water has to get over -- is 20 mm higher. The 480 mm boat has 47 mm of trimmed freeboard, not 26. Conservative and wrong, and it made freeboard look like the tightest margin on the boat when it is nowhere near. Found because two routes to the same number disagreed during the hull-length study.

---

## 2026-09-12 — Model the fasteners, the driveline and the wiring as geometry, and gate the hull penetrations

`model-the-fasteners-the-driveline-and-the-wiring`

Twelve M3 screws into ten brass heat-set inserts, a propeller shaft with a stuffing tube, a propeller, a transom rudder with its stock and tiller, a pushrod in a guide tube, and four wire runs -- all as solids in the assembly rather than numbers in a verdict. Plus a new gate, boat.hull_penetrations, that enumerates every hole through the shell or a watertight bulkhead and refuses more than one below the loaded waterline.

**Rejected**

- **screws threaded straight into the PETG** — a thread cut in printed plastic strips after a few cycles, and the hatch is the one interface opened every session to change the battery. Brass heat-set inserts cost nine dollars and their 4.6 mm OD is now a design input: every boss on the boat is 4.6 plus 2 mm of wall each side, which is why the hatch coaming widens to 8.6 mm at each screw.
- **discrete cylindrical boss posts** — in this print orientation the hull x axis is the build direction, so a post standing off the deck is a cylinder cantilevered horizontally off a wall and its underside needs support. Every boss on this boat is therefore a longitudinal RIB with a drilled bore, which is a vertical wall in the print.
- **boss-width ribs** — carrying 8.6 mm of boss width down the whole length of a rib cost 13 cm3 per rib to hold two M3 screws, and three of them pushed hull_mid past its print-time ceiling. The ribs are 2.4 mm webs that ramp up to boss width only where a screw lands, and ramp down to a 0.8 mm plinth at the ends so they start on the print bed.
- **zinc-plated screws** — zinc beside brass inserts in fresh water is a rust streak within a season, on the four fasteners that come out every session.
- **screwing the battery down** — a pack swapped every session should not be on threads. It sits between two printed chocks under a hook-and-loop strap, which is also what lets it slide fore and aft to trim the boat.

**Params:** `insert_od_mm`, `max_below_waterline_penetrations`  
**Claims:** `C20`, `P1`, `C9`

WHAT THE NEW GATE FOUND, immediately: two things below the waterline rather than one. The stuffing tube crosses the aft watertight bulkhead as well as the shell, and nothing anywhere had said so. The gate now separates the two -- the shell is what the pond is on the other side of and is capped at one; a bulkhead below the waterline is a second line of defence and is required to be declared and sealed rather than capped -- and both are written down with their sealing method.

SIX PENETRATIONS IN TOTAL. One through the shell below the waterline (the propeller shaft, unavoidable because the propeller has to be driven from inside). One through a bulkhead below the waterline (the same tube). Four above: the pushrod tube through the bulkhead and through the transom, the two rudder bracket screws, and the switch rod through the deck. Every boss on the boat is blind except the rudder bracket pair.

NO WIRE PIERCES A BULKHEAD. Motor, ESC, battery, receiver and servo are all between the two bulkheads, so all four runs stay inside the equipment bay. That is a layout decision and it is now visible as geometry.

COST: 6 printed parts to 7 (the motor clamp), printed mass 516 g to 586 g, print time 21.3 h to 24.2 h, BOM 374.50 to 397.50 USD. PLATES DID NOT MOVE: still 4 -- the clamp is 56 mm and shares a bed. Loaded freeboard went 26.5 mm to 25.8 mm on the extra 70 g, which still clears the 25 mm claim but is now the tightest margin on the boat.

The per-part print ceiling moved from 14 h to 17 h, and that is a threshold I relaxed. It is a judgement about the builder patience, not a physical property -- unlike the overhang allowance relaxed earlier in this project, which protected whether a part needs support and went back to the pack default as soon as the geometry allowed. hull_mid is a 190 mm tall hull section carrying a bulkhead, two deck rails, two coamings, a girder and five mounting ribs; 15.5 h is what that costs, and splitting it would add a part and a glued joint to a boat whose part count was just halved for watertightness.

---

## 2026-09-12 — Merge the loose plates into the hull segments: 13 parts and 8 plates down to 6 and 4

`merge-the-loose-plates-into-the-hull-segments-13`

The transom, both bulkheads, the centre girder, the shaft seat and two of the three deck panels stopped being separate parts and are now printed as part of the hull segment they used to be glued to. Each hull segment prints on a transverse face with its one solid cross-wall ON THE BED, which is what makes the merge possible at all: put a cross-wall at the far end of a segment and it becomes a 186 mm horizontal plate at the top of the print.

**Rejected**

- **merging the STEM CAP into hull_bow** — at the top of a bulkhead-down print it roofs the open cavity. fdm.bridge_span measured an 85 mm unsupported span across 2649 mm2. Printing that segment stem-down only moves the problem to the bulkhead, which is 132 mm wide rather than 85. It stays a separate 69 x 39 mm plate.
- **merging the BOW DECK into hull_bow** — it prints fine as a longitudinal wall, but hull_bow will not fuse to a single body, and as a separate body inside the same part its underside roofs the cavity with nothing in the same body beneath it: fdm.bridge_span, 19 mm, UNANCHORED. As its own part it lies flat on the bed and the question does not arise. Rejecting it also keeps the bow compartment open until the foam and the interior epoxy are in, and sealed air with no foam fails closed-loop.
- **putting each bulkhead on the segment it closes** — bulkhead_aft belongs to hull_mid and bulkhead_fwd to hull_bow, not to hull_aft and hull_mid. A bulkhead only merges into the segment whose print puts it on the BED.
- **a boolean union to make each merged part a single solid** — attempted, measured and rejected. Blender unions the bodies correctly by volume (0.95-0.98 of the inputs) but the result never survives the normalisation cad-solid applies on load: 2 non-manifold edges and 11 degenerate faces on hull_aft. manifold3d returns a watertight body in milliseconds whose STL round-trip is not watertight. geometry.fuse still tries and its guard still catches it, so the parts ship as overlapping bodies.

**Params:** `plate_proud_mm`, `merge_bite_mm`  
**Claims:** `C7`, `P1`

WHY IT IS AN IMPROVEMENT, not a convenience: a watertight bulkhead printed integral with its hull has no bond line to fail, and watertightness is the top physical risk on this boat (claim P1, one of five only water can settle). Seven glued joints became two.

WHAT IT COST, stated:
* Printed mass 480 g -> 516 g and print time 19.8 h -> 21.3 h. About 10 g of that is not real: overlapping bodies double-count their overlap, which inflates the modelled mass by roughly 2% in the conservative direction. The other ~26 g is: the integral decks are 2.0 mm where the loose panels were 1.4 mm, and the plates now cover the full section and stand 0.3 mm proud instead of being inset.
* An integral bulkhead can no longer be epoxy-filleted from both sides. It does not need to be, because it has no joint, but the hull-to-hull seam beside it is now filleted from one side only.
* hull_mid ships as seven overlapping bodies rather than one solid, and cad.wall_thickness measures 0.24 mm across an internal face between two of them. That gate was already failing before this change, on deck_mid, for the same reason.

Loaded freeboard moved 27.3 mm -> 26.5 mm and trim -1.22 -> -1.27 degrees on the extra 39 g. Both still pass. No claim that passed before this change fails after it.

---

## 2026-09-12 — Print every part standing on a transverse face or flat; no supports except at the stem

`print-every-part-standing-on-a-transverse-face-o`

Hull segments print standing on a transverse cut face. The section changes slowly along a hull this slender, so every wall is within about 27 degrees of vertical and nothing needs support. Plates and decks print flat. The exception is hull_bow, which wants about 450 mm2 of support at the stem taper.

**Rejected**

- **keel down** — the hull bottom is near-flat and the keel has rocker, so all but one line of it is an unsupported near-horizontal overhang. Unprintable.
- **deck down** — the same flat bottom, now a roof at the top of the print. Needs support over roughly 200 x 160 mm.
- **split on the centreline** — prints beautifully with zero support and puts a 400 mm glue seam along the keel: underwater, in the highest-stress region, and the single worst place on the boat to have a seam. Rejected on watertightness, claim P1, not on printability.
- **closed-ended hull segments** — a closed tube printed axially has to bridge its own section at one end, which is 160 mm of unsupported span. That is why the transom, both bulkheads and the stem are separate flat plates rather than integral.

**Params:** `bed_x_mm`  
**Claims:** `C7`

This decision is the reason the part count is thirteen rather than six. Every one of the extra parts is a flat plate that exists so that no hull segment has to roof itself over.

---

## 2026-09-12 — Fill the trim gap with closed-form arithmetic, not a solver

`fill-the-trim-gap-with-closed-form-arithmetic-no`

fluids-analytic names longitudinal trim as its own nearest omission. Rather than reaching for CFD, the gap is closed in model/hullform.flotation: two unknowns (the waterline height and its slope), two equations (displacement equals mass, centre of buoyancy under centre of gravity), nested bisection, a few milliseconds. It is exactly the sequence docs/EXTENSION_PROTOCOL.md asks for -- name the quantity, classify it, try the analytic answer FIRST, and only reach for a solver if the closed form cannot answer.

**Rejected**

- **install a CFD solver** — two gigabytes, an afternoon of setup, a meshing skill, and fifteen minutes a run, to answer a question a page of algebra answers exactly. Static trim is hydrostatics, not fluid dynamics: there is no flow in it. A solver here would be slower, less accurate and unfalsifiable.
- **use LCG-LCB offset as a proxy and skip the solve** — it was the first version and it is a proxy for the thing that matters rather than the thing. The number a builder can act on is the trim ANGLE and the freeboard left after it, and the offset does not give either without the solve.
- **ignore trim, since three hydrostatic gates were already green** — which is the failure the pack warns about by name. On this boat trim costs 3.8 mm of the lowest deck-edge freeboard, 15% of the claim. Level flotation reports 31.1 mm and the boat floats at 27.3 mm.

**Params:** `max_trim_deg`  
**Claims:** `C15`

Consequence worth stating: because the solve exists, the battery strap is a design feature. Sliding the battery is the trim adjustment, and boat.trim is what says how far.

---

## 2026-09-12 — Raise the build budget from 200 to 400 USD

`raise-the-build-budget-from-200-to-400-usd`

The 200 USD budget was mine, not the user s: the brief said Amazon-orderable and beginner-friendly and never named a number. With real prices for parts that meet the specs, the bill is 374.50 USD. bom.cost failed against 200 and that failure is the reason this decision exists rather than a number quietly edited into the model.

**Rejected**

- **200 USD, by cutting parts** — the three lines that would have to go are the ones the engineering depends on. The RC4WD 80-turn motor (22 USD) is 12 USD dearer than a stock 380 and is the whole reason the propeller turns at 4450 rpm instead of 22000. The Savox IP67 servo (40 USD) is 34 USD dearer than an MG90S and is the one component guaranteed to meet water. The Flysky set (54 USD) has no cheaper credible alternative. Cutting them buys 80 USD and costs the boat.
- **leave the budget at 200 and report the overrun** — the budget is a claim in the ledger, and a claim nobody intends to meet is noise in every future sweep. Either it moves with a reason or it is not a budget.

**Params:** `budget_usd`  
**Claims:** `C12`

FLAG FOR THE USER: this is the one number in the project that is purely my invention. If 400 USD is wrong, change budget_usd in model/boat.py and re-run; bom.cost will tell you what has to go. The 374.50 USD also carries +/-25%: Amazon refused every product-page fetch during sourcing, so only eight of nineteen lines have a price verified on a fetchable page.

---

## 2026-09-12 — Three compartments, a longitudinal centre girder, and closed-cell foam in the ends

`three-compartments-a-longitudinal-centre-girder`

The equipment bay is bounded by two watertight transverse bulkheads, leaving a sealed bow compartment and a sealed stern compartment. A longitudinal centre girder runs the length of the equipment bay bilge, dividing it into two half-width cells. Both sealed end compartments are filled with closed-cell foam.

**Rejected**

- **one open hull interior** — the free-surface correction on an undivided 163 mm wide bilge is i/V = 278 mm against a solid GM of 74 mm. Three millimetres of water in the bilge and the boat is upside down. This is not a margin problem, it is a sign problem.
- **transverse bulkheads only, no centre girder** — free-surface second moment is L*b^3/12: transverse bulkheads cut L, which is LINEAR, while a longitudinal division cuts b, which is CUBIC. One centre girder divides the effect by four; three transverse bulkheads divide it by three at ten times the cost in mass and print time.
- **sealed air compartments with no foam** — fluids lens 5: sealed air volumes fail closed-loop. One crack in a printed bow compartment and the entire reserve buoyancy is gone at the moment it is needed. Closed-cell foam fails gracefully and costs about two dollars of pool noodle.
- **a bilge pump** — an order of magnitude more cost, mass, current and failure modes than a bulkhead, and it does nothing about free surface while it is pumping.

**Params:** `bulkhead_positions`, `girder_height_mm`  
**Claims:** `C17`, `C18`

Every one of these came out of packs/fluids-analytic/lenses.md, run before any geometry existed. None of it would have shown up in a gate sweep, because fluid.metacentric reports solid GM and has no concept of a compartment.

---

## 2026-09-12 — Scale the traced hull to LOA 420 mm; keep the shape exactly

`scale-the-traced-hull-to-loa-420-mm-keep-the-sha`

The hull as drawn at LOA 300 mm displaces 73 g at the waterline the design tool drew. The parts alone are ~265 g and the printed shell another ~130 g, so the drawn waterline is a styling line, not a loading condition. Scaling the traced offsets by 1.40 (LOA 420 mm, deck beam 163 mm, depth 65.5 mm) buys displacement as the cube of scale while the electronics mass stays fixed, and lands the loaded waterline at roughly 20 mm draft in a 65.5 mm deep hull. The hull FORM is unchanged: every offset is the traced one times 1.40, so the boat the user liked is the boat they get, bigger.

**Rejected**

- **1.00 (LOA 300 mm as drawn)** — displaces 73 g at the drawn DWL and about 400 g at 23 mm draft, which leaves ~15 mm of freeboard with a +/-15% mass estimate riding on it. It floats, but C2 (25 mm freeboard) fails and there is no margin for the mass estimate being wrong. Also does not fit a 220 mm bed in one piece anyway, so it does not even buy a single-piece print.
- **1.50 (LOA 450 mm)** — hull halves come out 225 mm long and no longer fit a 220x220 bed, which breaks the "buildable at home" constraint for the most common printer class. 1.40 gives 210 mm halves, which fit with 10 mm to spare.
- **keep LOA 300 and cut mass instead** — the floor is real: the smallest usable 2S pack is ~75 g, a 370-class motor ~55 g, and the printed shell scales with surface area not with wishes. ~390 g is the floor and it still leaves 15 mm of freeboard.
- **redraw the hull deeper at LOA 300** — the user said they like this hull profile. Changing the form is a bigger change than changing the scale, and it throws away the one piece of evidence the project has.

**Params:** `hull_scale`  
**Claims:** `C1`, `C2`, `C3`  
**Evidence:** `hull-profile`

Displacement scales as s^3 and printed shell mass as roughly s^2, while motor, ESC, servo, receiver and battery do not scale at all. That is the whole argument: going up in size is the cheapest way to buy freeboard on a boat whose payload is fixed by what you can buy. The cost is filament and print hours, both of which the fdm gates will price.

---

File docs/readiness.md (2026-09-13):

# boaty — readiness (v0.1, 2026-09-13T02:27:38Z)

**v0.1 is NOT ready: 1 of 34 critical claims is unsettled — 1 failing (C8).** 20 of 34 claims are machine-verified against the current model. It is unverified in physical hardware: 5 claims need a real object (P1, P2, P3, P4, +1 more).

## What is PROVEN (machine-verified this run)

| Claim | Acceptance | Measured | Gate | Evidence |
|---|---|---|---|---|
| **C1** Floats at all-up mass consuming no more than 55% of the watertight hull volume | displaced volume fraction <= 0.55 | 0.3436 V_displaced/V_hull | `fluid.buoyancy` | *none written* |
| **C2** Deck edge stands at least 25 mm above the loaded waterline at the lowest point | freeboard >= 25.0 mm | 0.0496 m | `fluid.freeboard` | *none written* |
| **C3** Initial metacentric height GM is at least 15 mm at the loaded waterline | GM >= 15.0 mm | 0.0615 m | `fluid.metacentric` | *none written* |
| **C4** Righting arm GZ at 8 degrees of heel is at least 2 mm | GZ at 8 deg >= 2.0 mm | 0.0086 m | `fluid.righting_arm` | *none written* |
| **C5** Hull drag at the 0.8 m/s design speed is inside the static thrust the motor and propeller produce | drag force <= 3.0 N | 0.2714 N; 384000 Re | `fluid.drag`, `fluid.flow_regime` | *none written* |
| **C6** The drag correlation is being used inside the Reynolds range it was fitted over | Reynolds validity == 1.0 | 384000 Re | `fluid.flow_regime` | *none written* |
| **C7** Every printed part fits a 220x220x250 mm build volume with brim, carries at least 3 extrusion widths of wall, bridges n… | printability == 1.0 | 0.962 utilisation; 1.4 mm; 0.12 derated utilisation; 0.962 of limit; 0 problems; 0.00249 area fraction; 0 mm | `fdm.bed_fit`, `fdm.min_wall`, `fdm.layer_alignment`, `fdm.print_time_est`, `fdm.process_model_valid`, `fdm.overhang`, `fdm.bridge_span` | `/home/neuman/Documents/work/boaty/.atompipe/out/fdm-bed-fit-parts.txt`, `/home/neuman/Documents/work/boaty/.atompipe/out/fdm-overhang.txt` |
| **C9** No interference between the hull, the deck, and the placed motor, battery, ESC, servo, receiver and driveline | part interference == 0.0 clashing pairs | 0 pairs | `cad.clash` | `/home/neuman/Documents/work/boaty/.atompipe/out/cad-solid/clash_pairs.json` |
| **C10** The assembled boat fits inside a 560 x 230 x 170 mm envelope | bounding box <= 560.0 mm | 0.8571 utilisation; 0.857 fraction | `cad.bounding`, `boat.envelope` | *none written* |
| **C11** Every BOM line is orderable, priced in one currency, and has a known ship date | unorderable lines == 0.0 lines | 0 lines; 0 weeks; 0 lines | `bom.complete`, `bom.availability`, `bom.currency` | `/home/neuman/Documents/work/boaty/.atompipe/out/bom_complete.json`, `/home/neuman/Documents/work/boaty/.atompipe/out/bom_availability.json`, `/home/neuman/Documents/work/boaty/.atompipe/out/bom_currency.json` |
| **C12** Total build cost, excluding the printer, is at most 400 USD | rolled-up build cost <= 400.0 USD | 397.5 USD/unit | `bom.cost` | `/home/neuman/Documents/work/boaty/.atompipe/out/bom_cost.json` |
| **C13** No line forces a minimum-order overbuy worth more than 25 USD, and single-source risk is counted | MOQ overbuy <= 25.0 USD | 0 USD; 0 violations; 0 lines | `bom.moq`, `bom.process_rules`, `bom.single_source` | `/home/neuman/Documents/work/boaty/.atompipe/out/bom_moq.json`, `/home/neuman/Documents/work/boaty/.atompipe/out/bom_process_rules.json`, `/home/neuman/Documents/work/boaty/.atompipe/out/bom_single_source.json` |
| **C14** The wall thickness of every generated hull shell, measured from the exported mesh itself, matches the wall the model sp… | generated-vs-specified wall disagreement <= 0.15 fraction | 0.064 fraction | `boat.wall_agreement` | *none written* |
| **C15** The boat floats within 1.5 degrees of level, and the freeboard that survives the trim is still at least 25 mm | trim angle <= 1.5 deg | 0.867 deg | `boat.trim` | *none written* |
| **C16** The propeller shaft line leaves the hull through the hull bottom, the propeller disc clears the hull and the rudder, an… | driveline geometry violations == 0.0 violations | 0 violations | `boat.driveline` | *none written* |
| **C17** GM corrected for the free surface of bilge water in the equipment bay stays at least 10 mm | GM after free-surface correction >= 10.0 mm | 57.85 mm | `boat.free_surface` | *none written* |
| **C18** With the equipment bay completely flooded, the sealed fore and aft compartments still support the all-up mass plus the… | swamped freeboard >= 0.0 mm | 508.3 g | `boat.swamped` | *none written* |
| **C19** The hull is upright-stable and adequately floating in the EMPTY condition too, not only at design load | empty-condition GM >= 10.0 mm | 62.29 mm | `boat.empty` | *none written* |
| **C20** Every hole through the hull shell or a watertight bulkhead is enumerated with a sealing method, and at most one of them… | penetrations below the waterline <= 1.0 penetrations | 1 shell holes below waterline | `boat.hull_penetrations` | *none written* |
| **C21** Every drive and steering chain is continuous: no consecutive pair of members is more than 1 mm apart | worst gap in a drive or steering chain <= 1.0 mm | 0 mm; 0.3 mm | `boat.linkage_closed`, `cad.assembly_connected` | `/home/neuman/Documents/work/boaty/.atompipe/out/cad-solid/assembly_connected.json` |

Every row above is backed by at least one gate that actually ran and returned a pass — a skipped, errored or never-run gate can never be the evidence for a row. Where another gate also covers the claim and did **not** produce a pass, the row is marked **PARTIAL** and names it with the reason: the claim stands on the gates that ran, and you can see which ones did not.

## What is NOT verified

These need the real object. No gate in any pack can settle them, and no number of passing gates above changes that.

- **P1** The printed hull, the hull/deck joint and the stuffing tube keep the inside dry for a 30 minute run
  - **Test that would settle it:** measure water ingress <= 5.0 ml in 30 min on the built object and compare against the acceptance
  - **Why it matters:** No CFD run makes a printed seam watertight. FDM layer lines leak by capillary action even when the mesh is perfectly closed, and the shaft gland leaks by design unless it is greased. This is settled…
  - **Record the result:** `atompipe claim physical P1 --pass|--fail --detail "..." --when <ISO date>`
- **P2** The radio holds control to at least 50 m over open water
  - **Test that would settle it:** measure control range >= 50.0 m on the built object and compare against the acceptance
  - **Why it matters:** Water reflects, the receiver sits inside a closed hull, and antenna placement decides this. Only a range test settles it.
  - **Record the result:** `atompipe claim physical P2 --pass|--fail --detail "..." --when <ISO date>`
- **P3** Motor, ESC and battery stay under 60 C after a continuous 10 minute run
  - **Test that would settle it:** measure component temperature <= 60.0 deg C on the built object and compare against the acceptance
  - **Why it matters:** A sealed hull has no airflow. The thermal-analytic pack could model a steady-state lumped rise, but the inputs (real motor efficiency at this load, real internal air movement) are guesses, so a green…
  - **Record the result:** `atompipe claim physical P3 --pass|--fail --detail "..." --when <ISO date>`
- **P4** The boat holds a straight course without constant correction and turns inside a 2 m radius
  - **Test that would settle it:** measure turning radius <= 2.0 m on the built object and compare against the acceptance
  - **Why it matters:** Directional stability is a dynamic, free-running property. Nothing in any installed pack computes yaw stability, and a CFD install would not settle it either without a 6-DOF manoeuvring model. A pond…
  - **Record the result:** `atompipe claim physical P4 --pass|--fail --detail "..." --when <ISO date>`
- **P5** The hull does not warp off the print bed and the two hull halves actually mate
  - **Test that would settle it:** measure joint gap <= 0.3 mm on the built object and compare against the acceptance
  - **Why it matters:** Warp is a function of the machine, the enclosure, the ambient temperature and the filament batch. A printability gate says the geometry is printable; it does not say your printer will print it.
  - **Record the result:** `atompipe claim physical P5 --pass|--fail --detail "..." --when <ISO date>`

## Open gaps

None. Every measurable claim has at least one gate registered against it.

## Standing constraints

Carried on faith. None of this is proven; all of it is visible, which is the whole trade.

### Assumptions

- **A1** The hull shape pixel-traced from the screenshot is within +/-1.5 mm of the hull the design tool actually holds
  - The source is a PNG, not a file. Three independent scale estimates agree to 2.1%, which bounds the systematic error, but the curve traces are 4-5 px thick at 0.235 mm/px. If the user can export an STL or offsets from th…
- **A2** Component masses are the vendor listed figures and are within +/-15% of the parts that arrive
  - Listed masses on marketplace hobby parts are frequently the bare component without leads, connectors or mounting hardware. The mass budget carries a contingency line for this.
- **A3** The vertical centre of gravity is estimated from the placed component positions, not weighed
  - KG is the input GM is most sensitive to and the one nobody measures. C3 asks for 15 mm of GM against a pack default of 6.6 mm specifically to absorb this.
- **A4** PETG at 1.27 g/cm3. Printed part mass is mesh volume times a packing fraction: 1.00 for the hull shells, which are mode…
  - Getting this backwards is a 2x error on the mass every hydrostatic number depends on. A 1.4-2.0 mm slab at 4 perimeters and 0.24 mm layers is mostly perimeter and solid skin, so 0.88 rather than the 15% infill setting.…
- **A5** Design speed 0.8 m/s. Above that this hull is at or past hull speed and every drag number in this project stops meaning…
  - Hull speed for a 480 mm waterline is 1.25*sqrt(0.48) = 0.87 m/s, and 0.8 m/s is Froude 0.37. fluids-analytic computes no wave-making resistance, says so in its own PACK.md, and becomes a statement about a boat at rest a…
- **A6** Static thrust from the 35 mm propeller on the 80-turn motor at 7.4 V is at least 3.0 N
  - The weakest number in the drag chain and the only one with no source at all: a class figure, not a measurement and not a manufacturer curve. The MARGIN is what makes it survivable - computed resistance at the design spe…
- **A7** The equipment bay stays dry enough that bilge water is a few millimetres at most; the free-surface correction in C17 is…
  - C18 covers the fully flooded case separately and by a different mechanism (sealed, foam-filled end compartments). C17 is the small-water case: a stiffness question, not a flotation one. Conflating the two is how a boat…
- **A8** Print settings are a 0.4 mm nozzle, 0.24 mm layers, 4 perimeters, 15% infill, 60 mm/s, on a 220x220x250 mm class machine
  - Every printability verdict is against these. A 0.6 mm nozzle changes the minimum printable wall and therefore the deck thickness; a 180x180 bed does not fit hull_mid at all. Stated so the verdicts mean something to a re…

### Parameters with no recorded rationale

A number nobody can defend is a number the next agent will change — and then re-litigate, and then change back. `atompipe why <param>` is empty for each of these.

| Param | Value | Source | Protected by |
|---|---|---|---|
| `screw_d_mm` | 3 | *unsourced* | — |
| `screw_head_d_mm` | 5.5 | *unsourced* | — |
| `tube_inboard_x_mm` | 156 | *unsourced* | — |
| `shaft_d_mm` | 4 | *unsourced* | — |
| `coupler_d_mm` | 12 | *unsourced* | — |
| `coupler_len_mm` | 25 | *unsourced* | — |
| `prop_hub_d_mm` | 8 | *unsourced* | — |
| `prop_hub_len_mm` | 14 | *unsourced* | — |
| `rudder_stock_d_mm` | 3 | *unsourced* | — |
| `rudder_tiller_mm` | 20 | *unsourced* | — |
| `pushrod_d_mm` | 3.2 | *unsourced* | — |
| `pushrod_tube_od_mm` | 5 | *unsourced* | — |
| `pushrod_y_mm` | -50 | *unsourced* | — |
| `min_freeboard_mm` | 25 | *unsourced* | — |

## Failing / blocked
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

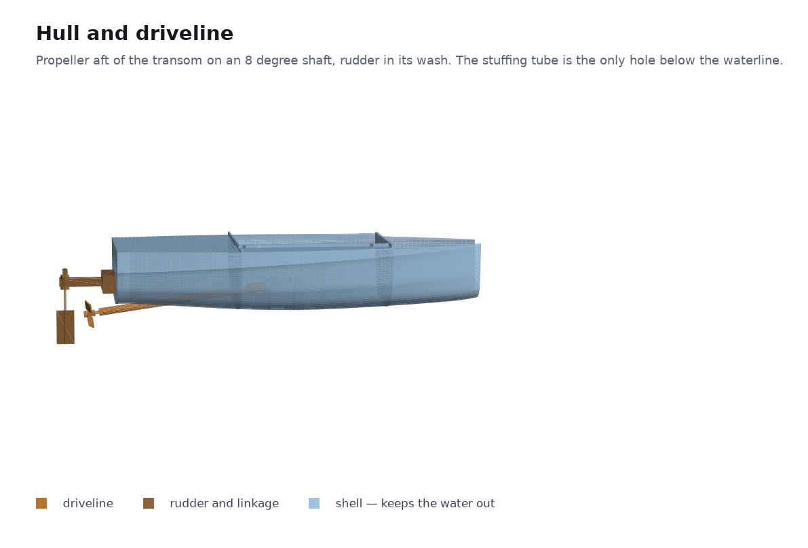
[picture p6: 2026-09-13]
renders/driveline.png

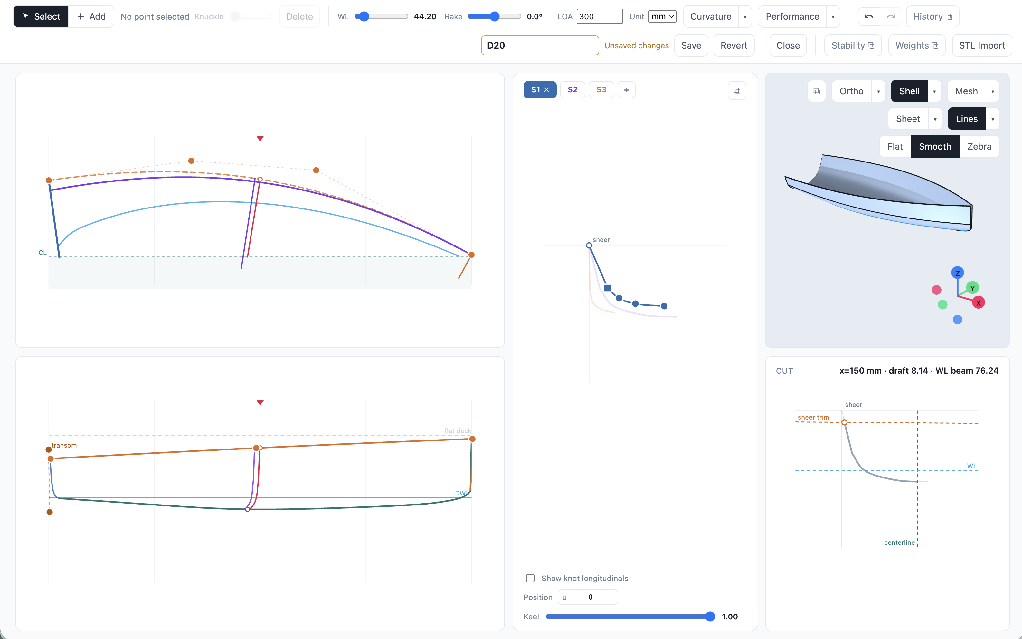
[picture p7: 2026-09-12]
brief/hull-profile.png

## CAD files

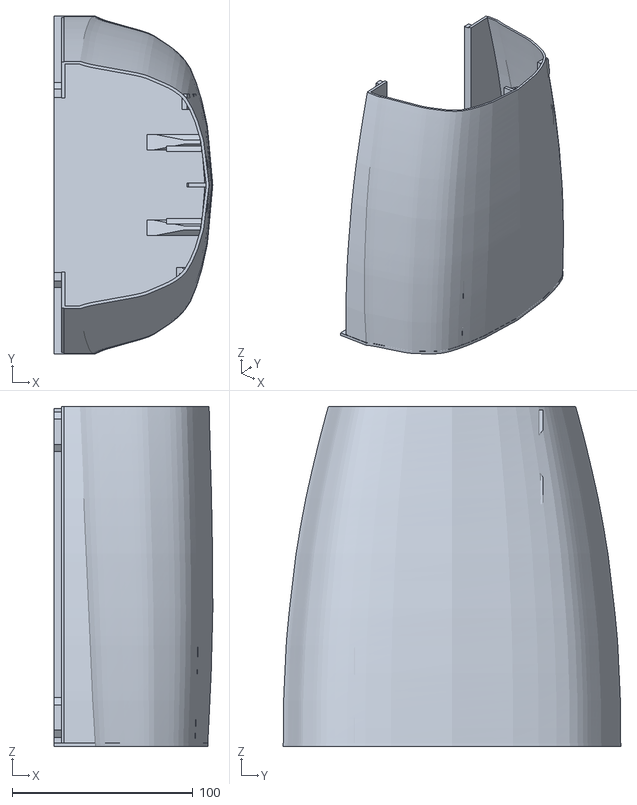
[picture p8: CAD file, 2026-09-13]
build/print/hull_mid.stl
87.7 x 186.8 x 188.0

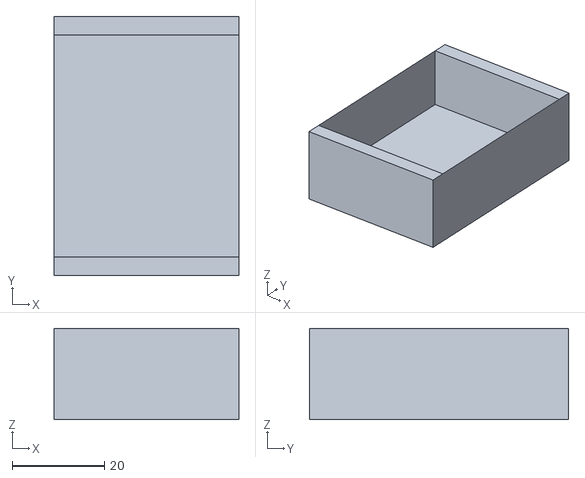
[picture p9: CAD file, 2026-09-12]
build/print/motor_clamp.stl
40.0 x 56.1 x 19.8

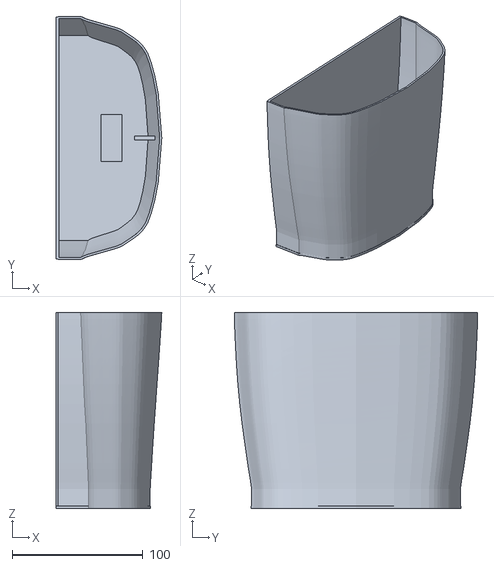
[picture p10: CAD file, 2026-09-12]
build/print/hull_aft.stl
80.8 x 186.2 x 150.0

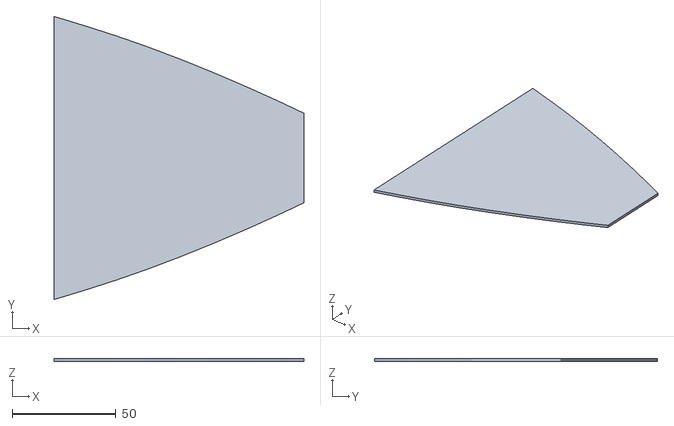
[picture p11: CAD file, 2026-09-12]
build/print/deck_bow.stl
120.8 x 136.8 x 1.40

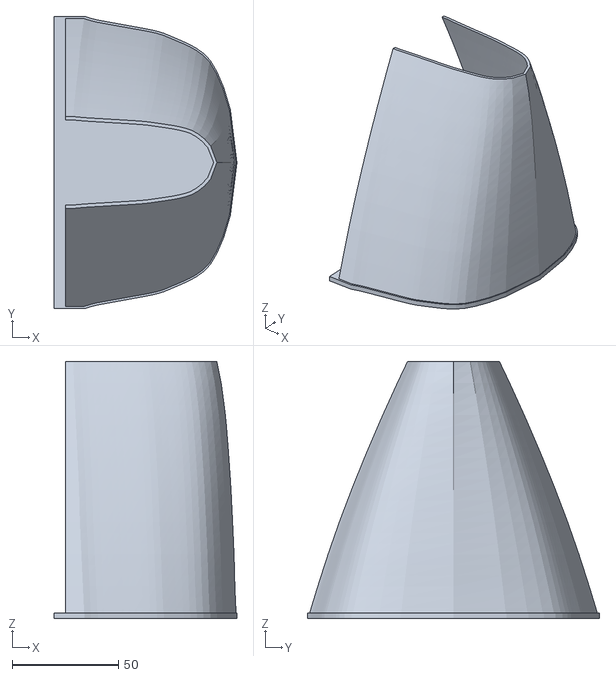
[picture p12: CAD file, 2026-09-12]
build/print/hull_bow.stl
86.0 x 137.4 x 120.8

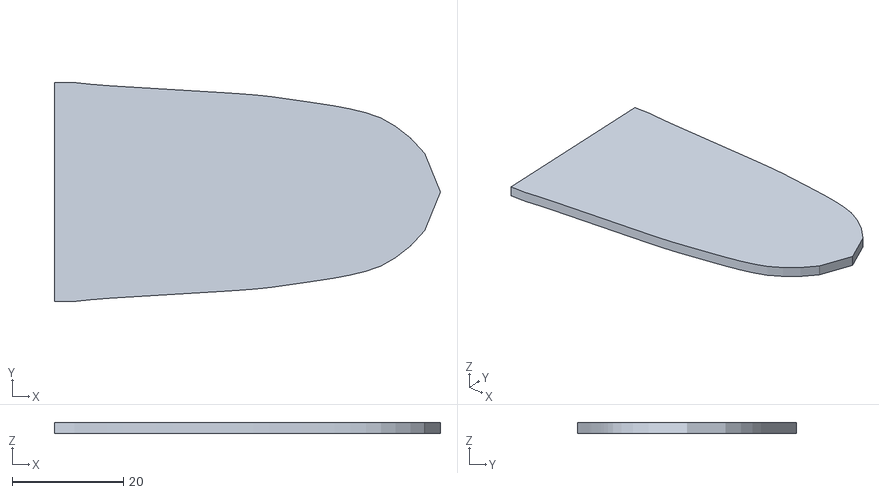
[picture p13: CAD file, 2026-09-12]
build/print/stem_plate.stl
69.3 x 39.3 x 2.00

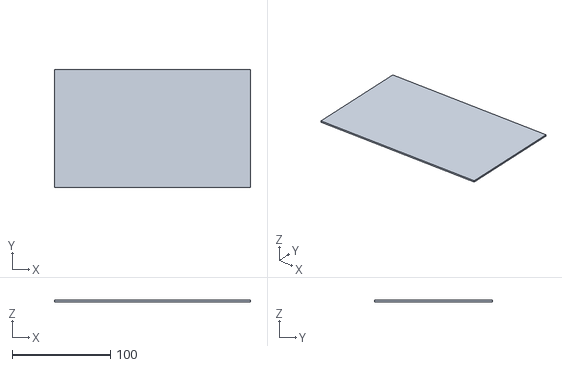
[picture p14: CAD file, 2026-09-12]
build/print/hatch_cover.stl
200.0 x 120.0 x 1.60

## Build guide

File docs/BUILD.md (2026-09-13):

<!-- GENERATED by tools/emit_docs.py from model/boat.py. Do not edit: change the model and re-run. -->

# Build order

Written in the order that lets you find a mistake while it is still cheap.

Six printed parts, two glued hull joints. The transom, both watertight bulkheads, the centre girder, the shaft seat and the aft deck are printed into the hull segments rather than glued on -- a bulkhead with no bond line cannot leak at the bond line.

## 1. Print and leak-test the three hull segments BEFORE anything else

Print `hull_aft`, `hull_mid` and `hull_bow`. Then, and this is the step every source agrees on and everybody skips: **fill each segment with water, stand it on a dry towel, and leave it two or three hours.** Mark every damp spot. Coat only what leaked, from the inside, and re-test.

Doing this now costs an evening. Doing it after the electronics are in costs the electronics.

## 2. Seal the inside

One or two thin brush coats of XTC-3D on the INSIDE of every segment, seams first. Thin coats: pooled epoxy adds mass without adding sealing, and mass is the budget this hull spends its freeboard out of.

`hull_aft` is open at its forward end and `hull_bow` at its bow end, which is how you get a brush into both sealed compartments. That access is the reason `stem_plate` and `deck_bow` are still separate parts.

## 3. Driveline, while hull_aft is still open

Drill the 10.2 mm stuffing-tube hole through the hull bottom at x = 52 mm at 8 degrees, and ream the matching bore through the shaft seat that is printed into the hull floor on that line. Pass the tube through both and **epoxy-fillet it on BOTH sides, inside and out**. Pack it one third to one half full of marine grease from the propeller end. This is the only penetration below the waterline and it is where boats actually sink.

## 4. Foam the ends, then close them

Fill the stern compartment (inside `hull_aft`) and the bow compartment (inside `hull_bow`) with closed-cell foam, around the stuffing tube and the pushrod tube. **Closed cell, not open**: open-cell foam is a sponge and becomes ballast. Then bond `stem_plate` into the bow and `deck_bow` onto hull_bow's sheer. Those compartments never open again, and they are what makes a swamped boat recoverable rather than gone.

## 5. Heat-set the inserts, before anything is glued

Ten M3 brass inserts: 4 in the hatch coaming at its widened zones, 4 in the motor cradle ribs, 2 in the servo shelf rib, 2 in the pad on the inside of the transom. Drill 4.2 mm, 6 mm deep, then push each insert in with a soldering iron at about 220 C, square, and let it cool before you load it.

Do it now, while every one of these is reachable with a straight arm. After the segments are joined, two of them are not.

## 6. Join the three segments

Two joints, both landing on a printed bulkhead face. Drill 2 mm pin holes through each joint face, three per joint, and dry-fit with 1.75 mm filament pins before any glue. Then CA the joints to tack them and epoxy-fillet each seam on the inside, through the hatch.

## 7. Fit out the equipment bay

- **servo** at x 178 mm, y -50 mm, z 34 mm above the keel
- **motor** at x 215 mm, y +0 mm, z 32 mm above the keel
- **esc** at x 256 mm, y +48 mm, z 40 mm above the keel
- **battery** at x 292 mm, y +0 mm, z 24 mm above the keel
- **switch** at x 312 mm, y +46 mm, z 24 mm above the keel
- **radio** at x 318 mm, y -40 mm, z 36 mm above the keel

The battery is STRAPPED, not glued. It is 292 mm from the transom in the model and sliding it is how you trim the boat: the model floats -0.87 degrees and every 10 mm of battery movement is worth roughly 0.1 degrees.

## 8. Rudder and steering

Bolt the rudder bracket to the transom with 2 x M3 stainless, through the two 3.4 mm holes, into the inserts in the transom pad. **Bed each screw in neutral-cure RTV under a nylon washer** -- these are the only two fasteners on the boat that go through the shell, and although they are 9 mm above the waterline they are 9 mm above the waterline in flat calm. Measure the bracket you are actually sent first: its hole spacing is not published.

Then feed the pushrod through its tube, clevis at each end, and set the servo to centre before you connect it.

## 9. Hatch

Lay the foam tape on the coaming's top face -- the coaming is printed into `hull_mid`'s deck rails and continues across both bulkhead tops -- and screw `hatch_cover` down onto it with four M3 self-tappers. Silicone-grease the tape every session. **Never glue the hatch shut**: it is the only way back into the boat.

## 10. Before the first sail

- Set the ESC to **Forward/Reverse**, not Forward/Brake/Reverse.
- Set **throttle failsafe to neutral**. A lost link with the throttle open is how boats end up in the reeds.
- Range-test on land with the hull closed, receiver where it will live.
- Refill the hull with water one more time and leave it an hour.
- Float it with the battery in and **check it sits level**. If it is down by the stern, slide the battery forward.
- First run: five minutes, close to shore. Open it, look for water, feel the motor and the ESC.

## What this boat will and will not do

Design speed **0.8 m/s**, which is Froude 0.37 on a 480 mm hull -- at hull speed. It is a displacement hull: past about 0.9 m/s it will squat by the stern, drag a large wake, and drink current without going meaningfully faster. That is not a fault, it is what the hull is.

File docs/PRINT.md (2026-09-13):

<!-- GENERATED by tools/emit_docs.py from model/boat.py. Do not edit: change the model and re-run. -->

# Print list

**7 parts, 589 g of filament, 24.3 h estimated.**

Material PETG, 0.4 mm nozzle, 0.24 mm layers, 4 perimeters, 15% infill, 60 mm/s, on a 220 x 220 x 250 mm bed.

STLs are in `build/`. **Print the files in `build/print/`, not the ones in `build/`** -- they are the same solids, but `build/print/` has each part already laid on the bed in the orientation every printability verdict was made against. The files in `build/` are in assembly coordinates and are there for the viewer and the clash check.

PETG needs four perimeters to be watertight untreated, which is why the shell is 1.6 mm. The interior epoxy coat is belt and braces on the one thing that cannot be fixed after assembly.

| Part | Print bbox mm | Mass g | Time h | Orientation | Support |
|---|---|---|---|---|---|
| `hull_mid` | 88 x 187 x 188 | 241 | 9.9 | standing on a transverse face | none |
| `hull_aft` | 81 x 186 x 150 | 184 | 7.6 | standing on a transverse face | none |
| `hull_bow` | 86 x 137 x 121 | 83 | 3.4 | standing on a transverse face | none |
| `hatch_cover` | 200 x 120 x 2 | 43 | 1.8 | flat on the bed, flipped | none |
| `deck_bow` | 121 x 137 x 1 | 18 | 0.7 | flat on the bed | none |
| `motor_clamp` | 40 x 56 x 20 | 16 | 0.6 | flat on the bed, flipped | none |
| `stem_plate` | 69 x 39 x 2 | 5 | 0.2 | standing on a transverse face | none |

Largest footprint 200 mm against 208 mm of usable bed once the brim is on.

## Plates

These 7 parts bin into **4 beds** of 220 mm (tools/render.py, shelf-packed, 8 mm between parts). Three of them are the full 186 mm beam of the boat on one axis, and two of those cannot share a 220 mm bed with anything, which is what sets the floor.

## Fasteners — where every screw goes

**M3 throughout, into brass heat-set inserts, never threaded into the plastic.** A thread cut in printed PETG strips after a few cycles and the hatch is opened every session. Stainless or nylon screws, not zinc-plated: zinc beside brass in fresh water is a rust streak within a season.

| Interface | Screws | Into | Blind? |
|---|---|---|---|
| hatch cover | 4 x M3 x 12 | inserts in the coaming, which widens to 8.6 mm at each screw | yes |
| motor clamp | 4 x M3 x 10 | inserts in the two cradle ribs | yes |
| servo | 2 x M3 x 10 | inserts in the servo shelf rib | yes |
| switch bracket | 2 x M3 x 8 | inserts in the switch shelf rib | yes |
| rudder bracket | 2 x M3 x 8 | inserts in a thickened pad on the INSIDE of the transom | **no — through the transom** |
| battery | none — hook-and-loop strap between two printed chocks | | |
| ESC, receiver | none — double-sided tape or hook-and-loop. Neither has mounting holes, and neither has to be located against anything | | |

12 inserts, 14 screws. Set the inserts with a soldering iron at about 220 C, square to the boss, and let them cool before loading. **Every boss is blind except the rudder bracket's two**, which is the whole point of the next section.

## Hull penetrations — every hole through a pressure boundary

The boat floats at **32.1 mm** of draft. A hole below that line is a leak path, so the layout puts everything it can above it. `boat.hull_penetrations` is the gate that keeps it that way -- it compares against the waterline the hydrostatics produce on the run, not a number typed beside it.

| Penetration | Through | Height above keel | vs waterline | Sealed by |
|---|---|---|---|---|
| `stuffing_tube_hull` | hull shell | 10 mm | **-23 mm — BELOW** | brass tube epoxy-filleted on BOTH faces of the shell and packed one third to one half full of marine grease from the propeller end |
| `stuffing_tube_bulkhead` | watertight bulkhead (aft) | 23 mm | **-9 mm — BELOW** | same tube, epoxy-filleted on both faces of the bulkhead |
| `pushrod_tube_bulkhead` | watertight bulkhead (aft) | 50 mm | +17 mm | brass tube epoxy-filleted on both faces |
| `pushrod_tube_transom` | hull shell (transom) | 50 mm | +17 mm | same tube, epoxy fillet outside and in, plus a smear of neutral-cure RTV round the pushrod at the outer end |
| `rudder_bracket_screws` | hull shell (transom) | 41 mm | +9 mm | M3 stainless through a neutral-cure RTV bead under the head and a nylon washer, into heat-set inserts in a thickened pad on the inside face of the transom |
| `rudder_stock_bearing` | external bracket (NOT a pressure boundary) | 38 mm | +6 mm | none needed: the bearing is a bronze bush in the bracket's boss, outside the hull, with nothing dry behind it |
| `switch_rod_deck` | deck | 82 mm | +50 mm | bushing bedded in neutral-cure RTV; the switch body stays inside and only the actuating rod passes through |

No wire pierces a watertight bulkhead: the motor, ESC, battery, receiver and servo are all between the two bulkheads, so all four runs stay inside the equipment bay. That is a layout decision, not luck.

## Holes to drill after printing

Nothing below is printed as a hole: a printed hole in a thin wall is a support problem and a drill is four seconds.

- **Stuffing tube**, through the hull bottom at x = 52 mm, at 8 degrees down-aft, and through `shaft_block` on the same line. **10.2 mm** for a 9.5 mm tube plus an epoxy fillet.
- **Pushrod tube**, through `bulkhead_aft` and `transom_plate` at the same height, above the waterline. 3.2 mm.
- **Limber holes**, 6 mm, through the foot of the centre girder inside `hull_mid`, every 40 mm, so bilge water can reach one place instead of two.
- **Hatch screws**, 4 x 2.5 mm pilot through the lid into the coaming for M3 self-tappers.
- **Insert bores**, 4.2 mm, 6 mm deep: 4 in the hatch coaming (at its widened zones), 4 in the motor cradle ribs, 2 in the servo shelf rib, 2 in the switch shelf rib, 2 in the transom pad. Twelve in total.
- **Clearance holes**, 3.4 mm: 4 through the hatch cover, 4 through the motor clamp's feet, 2 through the rudder bracket, 2 through the transom for the rudder bracket.
- **Joint pins**, 2 mm through each of the two hull-to-hull joint faces, for 1.75 mm filament shear pins. Three per joint. There are only two joints left: the bulkheads that used to be loose plates are now printed into the segments.
- **Rudder bracket**, to the transom, to suit the bracket you get: its hole spacing is not published by the vendor. Measure first.

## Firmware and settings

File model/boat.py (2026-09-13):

# SPDX-License-Identifier: Apache-2.0
"""boaty -- a 3D-printed RC displacement boat. The only source of truth.

Everything downstream -- STLs, the bill of materials, the mass budget, every number
the gates read, the readiness report and the site -- is generated from `Config` and
`build()`. Nothing is typed twice (METHOD rules 1 and 2).

Read `model/hullform.py` first for the frame. In one line:

    x = 0 at the TRANSOM, +x forward; y = 0 on the centreline; z = 0 AT THE LOWEST
    POINT OF THE KEEL, +z up.

Every draft, KG, KB and freeboard below is from that z = 0. The design tool's own
waterline is not a datum here -- it was a slider position on a screenshot, and the
boat floats where its mass says it floats, which is the single most important
finding in this project.

Units: millimetres, grams, newtons, degrees inside this file. `build()` also emits
SI keys (metres, kg, m^2, m^3, m^4) because fluids-analytic is SI-only and
unprefixed, and a factor of a thousand in a waterplane inertia looks exactly like a
metacentric height of forty metres -- which its PACK.md warns about by name.
"""
from __future__ import annotations

import hashlib
import json
import os
import sys
from dataclasses import dataclass, asdict, field, fields

sys.path.insert(0, os.path.dirname(os.path.abspath(__file__)))

import numpy as np
import trimesh

import hullform
import geometry as G

ROOT = os.path.dirname(os.path.dirname(os.path.abspath(__file__)))
BUILD = os.path.join(ROOT, "build")

G_ACCEL = 9.80665
RHO_FRESH = 998.0            # kg/m^3 at 20 C. Pond water. Sea water would be 1025
                             # and every draft here would be 2.7% shallower, which
                             # is a change nobody would notice and nobody should rely on.


# --------------------------------------------------------------------------- #
# Materials
# --------------------------------------------------------------------------- #
MATERIALS = {
    # PETG over PLA is not a close call for this part. PLA absorbs water, creeps,
    # and goes brittle; a PLA hull left in a hot car delaminates at the layer lines,
    # which on a boat is the failure that matters. ABS would be better again and is
    # not printable on an open-frame machine without warping a 200 mm part.
    "petg": {"density_g_cm3": 1.27, "E_mpa": 1800.0, "yield_mpa": 30.0},
    "pla":  {"density_g_cm3": 1.24, "E_mpa": 2800.0, "yield_mpa": 35.0},
}


# --------------------------------------------------------------------------- #
# Components. Mass and size are what the hydrostatics and the clash check stand on,
# so each line carries where the number came from. `price_usd` and the vendor fields
# feed the sourcing pack.
#
# CONFIDENCE is per-line and honest: "listed" means a vendor listing states it,
# "class" means it is the typical figure for that class of part and the specific
# item may differ by 10-20%. Claim A2 carries the consequence.
# --------------------------------------------------------------------------- #
@dataclass
class Part:
    key: str
    desc: str
    mass_g: float
    size_mm: tuple                  # (x, y, z) bounding box as installed
    price_usd: float
    qty: int = 1
    vendor: str = "Amazon"
    mpn: str = ""
    search: str = ""
    lead_days: int = 3
    moq: int = 1
    confidence: str = "class"
    note: str = ""
    cls: str = "cots"
    manufacturer: str = ""
    placed: bool = True             # does it get a clash box inside the hull
    currency: str = "USD"
    lifecycle: str = "active"
    second_source: str = ""


def _manufacturer_of(desc: str) -> str:
    """First token of the description, which for these lines is the brand. Derived
    rather than typed a second time (rule 2): `manufacturers` in the BOM is what
    single-source risk is counted from, and a typo'd brand silently becomes a second
    source that does not exist."""
    first = desc.split(",")[0].split()[0]
    return first if first[:1].isupper() else "generic"


def _parts() -> list:
    """The bill of materials.

    Prices are USD, Amazon US unless the vendor column says otherwise. Several were
    price-verified on the manufacturer's or a fetchable retailer's own page and say
    so; Amazon itself refused every product-page fetch during research, so Amazon
    prices are ESTIMATES and the roll-up is +/-25%, not a quote. The ASINs are real
    -- each came from a live amazon.com/dp/ URL -- but every line also carries a
    search string, because a stale ASIN is worse than useless and a search is not.
    """
    return [Part(**{**asdict(p), "manufacturer": p.manufacturer or _manufacturer_of(p.desc)})
            for p in _parts_raw()]


def _parts_raw() -> list:
    return [
        Part("motor", "RC4WD Z-E0001 540 crawler brushed motor, 80 turn", 156.0,
             (50.0, 35.5, 35.5), 22.0, mpn="B00CR32LZ0",
             search="RC4WD 540 Crawler Brushed Motor 80T Z-E0001",
             confidence="spec verified; price estimated",
             second_source="INJORA 540 80T; INJORA 55T (B08CSJTDGH) runs faster than ideal",
             note="80 turns: 5500 rpm no-load at 7.2 V, best efficiency 4450 rpm at 1.38 A. "
                  "That is the entire reason for this motor. A STOCK 380 or 540 is about "
                  "3000 rpm/V, i.e. 22000 rpm on 2S -- four to six times what a 35 mm prop "
                  "on a displacement hull wants -- and running it at quarter throttle is "
                  "not the same thing as choosing the right motor. "
                  "REJECTED: Mabuchi RS-380SH-20150, 71 g and 916 rpm/V, which is 85 g "
                  "lighter AND the right speed. It has a 2.3 mm shaft, and essentially "
                  "every RC-boat coupler sold is 3.17 mm. The 2.3-to-4 mm coupler exists "
                  "and no reliable US listing could be confirmed for it. A part you cannot "
                  "order is a part you do not have; the 85 g is bought back with hull scale."),
        Part("esc", "Fire Phoenix 'New Rain' 60 A waterproof brushed ESC, single motor", 44.0,
             (42.0, 28.0, 25.0), 26.0, mpn="B08B5TTFVV",
             search="Fire Phoenix New Rain 60A waterproof brushed ESC RC boat single motor",
             confidence="spec verified; price estimated",
             second_source="Hobbywing QuicRun WP-1060 (B0CNT14KMH), 39 g, IP67, better built, ~$30",
             note="ORDER THE SINGLE-MOTOR VARIANT -- the listing has a single/dual selector. "
                  "60 A on a 2-4 A load is deliberate oversizing and it IS the thermal "
                  "design: the hull is sealed, there is no airflow at all, and conformal "
                  "coating makes dissipation worse. Oversize the ESC rather than thin the "
                  "coating. MUST HAVE REVERSE; set Forward/Reverse, not "
                  "Forward/Brake/Reverse, so there is no drag brake. "
                  "REJECTED: the $12 'GoolRC 320A' class. The 320 A is fantasy -- documented "
                  "thermal cutoff in about a minute at full power on 3S, and 1.5 kHz drive "
                  "PWM. In a sealed hull that is a recovery by paddle."),
        Part("servo", "Savox SW-0250MG waterproof digital micro servo, IP67", 25.0,
             (32.5, 14.0, 29.5), 40.0, mpn="B0C11MYL3W",
             search="Savox SW-0250MG waterproof digital micro servo",
             confidence="spec verified; price estimated",
             second_source="Miuzei MG90S metal gear (B0BWJ41FZB), 14 g, ~$6 -- NOT waterproof",
             note="5.0 kg-cm at 6 V, IP67. The rudder servo is the one item in a boat that "
                  "is guaranteed to meet water eventually, and 2.5x the torque of an MG90S "
                  "is margin for a rudder tube stiffened with grease and grit. "
                  "MOUNTING LUG SPACING IS NOT PUBLISHED by Savox -- measure it with "
                  "calipers before you print the servo mount."),
        Part("radio", "Flysky FS-GT5 2.4 GHz pistol-grip transmitter with FS-BS6 receiver", 9.0,
             (30.0, 22.0, 16.0), 54.0, mpn="B07C16BX6L",
             search="Flysky FS-GT5 FS-BS6 transmitter receiver",
             confidence="price VERIFIED $53.90 at HobbyMate",
             second_source="RadioLink RC4GS V3 + R6FG (B09YR4SN17); Spektrum DX3 Smart, $89.99 verified",
             note="The mass and size are the RECEIVER; the transmitter is not in the boat. "
                  "Pistol grip is the right ergonomics for a surface vehicle. Per-channel "
                  "failsafe: SET THROTTLE FAILSAFE TO NEUTRAL. A lost link with the throttle "
                  "stuck open is how boats end up in the reeds. "
                  "REJECTED: RadioMaster Pocket ELRS. No receiver in the box, TX and RX "
                  "firmware majors must match to bind, and most ELRS receivers are CRSF only "
                  "with no PWM output for a servo. Great radio, wrong first radio."),
        Part("battery", "Zeee 2S 7.4 V 2200 mAh 50C shorty LiPo, XT60", 98.0,
             (73.0, 34.0, 18.5), 15.5, mpn="B0BYNKBKGT",
             search="Zeee 2S 2200mAh 50C shorty XT60",
             confidence="price VERIFIED $30.99 for 2 at zeeebattery.com",
             second_source="Ovonic 2200 2S (B0CF9JRPZL) 87x33x18 mm 118 g; Gens Ace 2200 (B09Z1YLQ8G)",
             note="Second heaviest item, and the one that sets both KG and LCG, so it lives "
                  "on the hull floor on the centreline. The SHORTY pack matters: 73 mm long "
                  "against 87-105 mm for a standard 2200, which buys the longitudinal room "
                  "to trim the boat by sliding it. 35-60 min at a 2-4 A cruise. "
                  "REJECTED: 5200 mAh 2S hardcase -- 261 g and 138 mm long."),
        Part("charger", "HTRC B6 V2 80 W balance charger", 0.0, (0.0, 0.0, 0.0), 28.0,
             mpn="B08DV5PSD8", search="HTRC B6 V2 80W balance charger",
             confidence="price VERIFIED $27.99 Banggood US", placed=False,
             note="Not in the boat. CONFIRM the AC adapter is in the box: the unit itself is "
                  "DC 11-18 V input. Charge in a LiPo bag at 1C (2.2 A), never unattended."),
        Part("shaft_kit", "uxcell 4 mm drive shaft assembly: 250 mm shaft, 200 mm stuffing "
                          "tube, universal joint for a 3.17 mm motor shaft, nylon prop, dog, nut",
             80.0, (250.0, 10.0, 10.0), 18.0, mpn="B07Q3286KM",
             search="uxcell 4mm Drive Shaft L250mm Sleeve L200mm 3.17mm Motor Shaft",
             confidence="price VERIFIED $17.59 at Harfington (uxcell's own store)", placed=False,
             second_source="generic 'RC boat 4mm drive shaft' sets, sleeve OD 10 mm (B07RK979GW)",
             note="STUFFING TUBE OD IS 9.5 mm -- drill the hull at 10.2 mm for clearance plus "
                  "an epoxy fillet. The 130 mm short kit does NOT come with a 3.17 mm joint; "
                  "only the 250 mm and longer kits do, which is the second independent reason "
                  "this boat is 420 mm rather than 300 mm. "
                  "Not clash-checked as a box: it lives on the shaft axis and boat.driveline "
                  "settles it instead."),
        Part("prop", "3-blade brass scale propeller, 35 mm diameter, M4", 14.0,
             (16.0, 35.0, 35.0), 13.0, mpn="B0D814JF9S",
             search="RC Boat 3-Blades Propeller Copper M4 35mm scale marine tug",
             confidence="spec verified; price estimated", placed=False,
             note="Replaces the nylon prop in the shaft kit. The bundled nylon props run "
                  "pitch/diameter 1.4 to 1.9, which is RACING pitch; a displacement hull "
                  "wants about 0.9 to 1.1. Keep the nylon one as the spare -- it works, at "
                  "lower throttle."),
        Part("rudder", "Hobbypark aluminium transom-mount rudder, 75 mm, frame 60 x 43 mm", 37.0,
             (60.0, 14.0, 75.0), 16.0, mpn="B07FS9KBYZ",
             search="Hobbypark aluminum RC boat rudder 75mm transom mount",
             confidence="spec verified; price estimated", placed=False,
             second_source="95 mm version (B07FS2G9KN) for boats up to 850 mm",
             note="TRANSOM mount, and that is forced rather than chosen. The bottom-mount "
                  "scale rudders (62x30 mm pad, 6 mm sleeve) bolt to the hull BOTTOM, which "
                  "would put the blade ahead of a propeller that has to sit aft of the "
                  "transom on a hull this shallow -- and a rudder in the prop's INFLOW is "
                  "not steering, it is drag. Rated for 400-600 mm boats. "
                  "MOUNTING HOLE SPACING IS NOT PUBLISHED: measure before drilling."),
        Part("linkage", "Pushrod, clevises and 3 mm brass pushrod tube", 12.0,
             (140.0, 6.0, 6.0), 8.0, search="RC pushrod linkage clevis set 2mm brass tube",
             confidence="class", placed=False,
             note="The pushrod runs from the servo in the equipment bay through a brass tube "
                  "epoxied through the aft bulkhead and the transom ABOVE the waterline, to "
                  "the rudder tiller. Epoxy-fillet both ends of the tube; the aft compartment "
                  "stays sealed."),
        Part("switch", "RC on/off switch with an external aluminium control rod and "
                       "mounting bracket", 14.0,
             (48.0, 18.0, 14.0), 12.0, mpn="B0CCTS8BW3",
             search="RC receiver on off switch aluminum control rod boat",
             confidence="class",
             note="The switch body stays inside the sealed hull and a rod through a small "
                  "bushing flips it from outside. A conventional switch harness is a hole in "
                  "the deck with a moving part in it. NEVER put a mechanical switch in the "
                  "battery-to-ESC path; switch the receiver/BEC side only."),
        Part("hatch_seal", "Self-adhesive silicone or EPDM closed-cell foam tape, 10 x 3 mm", 8.0,
             (0.0, 0.0, 0.0), 9.0,
             search="self adhesive silicone foam tape 10mm x 3mm closed cell",
             confidence="class", placed=False,
             note="Prusa measured PRINTED flexible-filament gaskets failing completely and "
                  "O-rings being the most reliable hatch seal. Closed-cell foam tape on the "
                  "deck land, compressed by four M3 screws, is the buildable version. "
                  "Silicone-grease it every session. NEVER glue the hatch shut."),
        Part("foam", "Closed-cell polyethylene foam for the sealed end compartments", 14.0,
             (0.0, 0.0, 0.0), 7.0, search="closed cell polyethylene foam block",
             confidence="class", placed=False,
             note="A pool noodle works. CLOSED cell, not open: open-cell foam is a sponge and "
                  "becomes ballast. Sealed air alone fails closed-loop -- one crack and the "
                  "entire reserve is gone at the moment it is needed."),
        Part("grease", "Dynamite marine grease, 5 oz, for the stuffing tube", 12.0,
             (0.0, 0.0, 0.0), 12.0, mpn="B00XUM0OQK", search="Dynamite Marine Grease 5 oz",
             confidence="class", placed=False,
             note="NOT thin silicone grease -- that is for O-rings and the hatch seal. The "
                  "stuffing tube is packed one third to one half full with thick tacky "
                  "marine grease, injected from the prop end; the grease is a physical plug "
                  "as much as a lubricant. Overfilling just adds drag."),
        Part("rtv", "Permatex 82180 Ultra Black RTV, neutral cure, sensor safe", 10.0,
             (0.0, 0.0, 0.0), 9.0, mpn="B0002UEN1U",
             search="Permatex 82180 Ultra Black sensor safe RTV",
             confidence="price VERIFIED $8.99 Summit Racing", placed=False,
             note="NEUTRAL CURE, and this is not a preference. Acetoxy-cure RTV -- which is "
                  "most clear silicone, including Permatex 66B and GE Silicone 1 -- releases "
                  "acetic acid as it cures, and in a sealed hull the vapour condenses on IC "
                  "leads and attacks copper and solder. If you substitute: GE Silicone II is "
                  "neutral cure, GE Silicone 1 is not, and the packaging does not make that "
                  "obvious."),
        Part("epoxy", "Smooth-On XTC-3D brush-on epoxy coating, 6.4 oz", 30.0,
             (0.0, 0.0, 0.0), 28.0, mpn="B09MSPD3MK", search="Smooth-On XTC-3D 6.4 oz",
             confidence="coverage verified at Smooth-On; price estimated", placed=False,
             note="THIS is what makes an FDM hull watertight. The printed seam is not the "
                  "seal; the fillet over it is. 1 oz covers about 645 cm2, so 6.4 oz is two "
                  "coats on this boat with margin. Brush it INSIDE, seams first, thin coats "
                  "-- pooled epoxy adds mass without adding sealing. "
                  "REJECTED: 5-minute hardware-store epoxy, too viscous to wick into a layer "
                  "line; and any 'table top' casting resin, which is a bar-top product rated "
                  "at 1/8 inch and far too heavy."),
        Part("coating", "MG Chemicals 422B silicone conformal coating, 55 mL with brushes", 10.0,
             (0.0, 0.0, 0.0), 24.0, mpn="B008O9YIV6",
             search="MG Chemicals 422B silicone conformal coating 55 mL brush",
             confidence="class", placed=False,
             note="Brush-on bottle, not aerosol. MASK the ESC heatsink pad, the BEC header "
                  "and every connector you will unplug. Coating measurably impedes heat "
                  "dissipation, which is why the ESC is oversized instead of the coating "
                  "thinned. It buys splash protection, not submersion."),
        Part("fasteners", "M3 A2 stainless pan-head screws 6/8/10 mm, washers, "
                          "hook-and-loop battery strap", 22.0,
             (0.0, 0.0, 0.0), 12.0,
             search="M3 A2 stainless pan head screw assortment 304",
             confidence="class", placed=False,
             note="STAINLESS or nylon, never zinc-plated. Zinc plating in fresh water "
                  "beside brass inserts is a rust streak within a season, and four of "
                  "these come out every time you change the battery. Fourteen are used: "
                  "4 for the hatch, 4 for the motor clamp, 2 for the servo, 2 for the "
                  "switch bracket, 2 for the rudder bracket."),
        Part("inserts", "M3 brass heat-set threaded inserts, 4.6 mm OD x 5.7 mm long", 11.0,
             (0.0, 0.0, 0.0), 9.0,
             search="M3 brass heat set threaded insert 4.6mm OD 5.7mm knurled",
             confidence="class", placed=False,
             note="NOT screws threaded straight into PETG: a thread cut in printed "
                  "plastic strips after a few cycles, and the hatch is the one "
                  "interface opened every session. THE OD IS A DESIGN INPUT -- every "
                  "boss on this boat is 4.6 mm plus 2 mm of wall each side, which is "
                  "why the hatch coaming is 9 mm wide and not 5. Buy a different "
                  "insert and the bosses are wrong. Twelve are used; buy 50. Set them "
                  "with a soldering iron at about 220 C, square, and let them cool "
                  "before loading."),
        Part("wire", "Silicone-insulated wire, 16 AWG and 22 AWG, plus a servo "
                     "extension lead", 26.0,
             (0.0, 0.0, 0.0), 13.0,
             search="silicone wire 16 AWG 22 AWG flexible RC wire kit",
             confidence="class", placed=False,
             note="Silicone, not PVC: it stays flexible in the cold and survives being "
                  "pushed around inside a hull. All four runs stay inside the equipment "
                  "bay -- motor, ESC, battery, receiver and servo are all between the "
                  "two bulkheads -- so NO wire pierces a watertight bulkhead and none "
                  "of them is a hull penetration. That is a layout decision, not luck."),
    ]
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

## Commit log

2026-09-12 a 480 mm RC boat, from one screenshot
    Developed from a single screenshot of a hull-design tool, using atompipe, by an
    agent that had never seen that codebase.
    The hull as drawn is 300 mm and displaces 73 g at the waterline the tool drew.
    The parts alone weigh 591 g — that waterline was a slider position, not a loading
    condition. Displacement goes as the cube of length and a motor does not scale at
    all, so the hull is scaled 1.6x to 480 mm with the FORM untouched: every offset is
    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
    [bulkhead_aft.stl, bulkhead_fwd.stl, deck_aft.stl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]
2026-09-12 six parts, four plates: merge the loose plates into the hull segments
    The transom, both watertight bulkheads, the centre girder, the shaft seat and
    the aft deck are now printed INTO the hull segments they used to be glued to.
    parts 13 -> 6
    plates 8 -> 4 (tools/render.py, 220 mm beds)
    joints 7 -> 2 glued hull-to-hull seams
    print 19.8 h -> 21.3 h, 480 g -> 516 g
    It is a watertightness change, not a tidiness one: a bulkhead printed integral
    with its hull has no bond line to fail, and P1 -- does the hull stay dry -- is
    the top physical risk on the boat and one of five claims only water can settle.
    It works because every segment prints standing on a transverse fac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
    [bulkhead_aft.stl, bulkhead_fwd.stl, deck_aft.stl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]
2026-09-12 screws, driveline and wires as geometry; gate the hull penetrations
    The owner could not find a propeller, a screw or a wire in the renders because
    none of them existed. The driveline was four numbers in boat.driveline, so
    cad.clash had never seen a propeller, a stuffing tube or a rudder, and neither
    had a reader.
    Now modelled as solids, in the assembly and in the clash set:
    driveline stuffing tube, prop shaft, coupler, 3-blade propeller
    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
    [hull_aft.stl, hull_mid.stl, motor_clamp.stl]
2026-09-13 close the steering chain; gate closure; settle the one-piece hull question
    STEERING WAS NOT CONNECTED, and the owner found it by measuring my own GLB.
    The rudder had no stock and no tiller arm. The blade hung 43 mm below its own
    bracket, attached to nothing, and the pushrod stopped 11 mm short of the nothing
    it was pushing. Every gate was green.
    before after
    pushrod -> bracket GAP 11.0 mm every joint in both chains: 0.00 mm
    bracket -> blade GAP 42.9 mm
    The stock now runs from the bottom of the blade, through a bearing boss in the
    bracket, up to a tiller at pushrod height, and the pushrod ends on it. The
    bearing is a bronze bush outside the hull wit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
    [boat.py]
2026-09-13 mount the switch; retire the local linkage gate; kill the NaN and its cause
    Two defects, both found by tooling, neither by reading.
    1. THE SWITCH WAS HELD BY NOTHING. cad.assembly_connected found it floating
    5.50 mm from the nearest part in a 31-body assembly where every other body
    touched something. It now sits on a longitudinal shelf rib in hull_mid with two
    M3 screws into heat-set inserts, declared as a required contact.
    What was holding it in my head: tape, filed mentally with the ESC and receiver,
    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
    [hull_mid.stl]
